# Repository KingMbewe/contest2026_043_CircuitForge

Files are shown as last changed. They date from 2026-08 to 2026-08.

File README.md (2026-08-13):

<b>English</b> | <a href="README_zh.md">中文</a>

# VelaPaw — an on-device AI multi-pet smart feeder

**Team:** CircuitForge (`contest2026_043`) · **Track:** AI Hardware Product Innovation (AI 硬件产品创新)
**Platform:** openVela (NuttX) on a Waveshare **ESP32-S3-Touch-LCD-3.5-C**

---

## Demo Video

<!-- TODO: paste the GitHub-generated CDN URL here after uploading VelaPaw_Demo.mp4 through the GitHub web editor (drag the file into this README's edit box on github.com). GitHub renders it as a native inline player automatically. -->

https://github.com/user-attachments/assets/88f0cb95-1f25-4606-aad2-784a267a6f7b

▶ If the embedded video above doesn't load, [download it directly](VelaPaw_Demo.mp4) (58MB, MP4). We recommend you download the video for better quality.

---

## 1. What it is

**VelaPaw is a smart pet feeder that recognizes *which* pet is at the bowl and dispenses that individual pet's scheduled meal — with every bit of AI running on the device itself. No cloud, no phone, no account.**

In a multi-pet home, a normal timed feeder can't tell the cats apart, so the greedy one eats everyone's food and portion control is impossible. VelaPaw solves this the way a human would: it *looks* at the animal, identifies it, and feeds it only its own ration, at its own mealtimes. Because the camera, the neural networks, the clock, and the dispenser are all self-contained, it keeps working with the internet down and never sends images of your home anywhere.

**Highlights**

- 🐾 **Per-pet identification** — an on-device INT8 neural network recognizes each enrolled pet by face, not by a tag or collar.
- 🍽️ **Recognition-gated feeding** — a pet is fed only when it is *recognized at the bowl* **and** one of *its* meals is due (and not skipped), at most once per meal per day. Each meal slot has its own **skip-meal** toggle.
- 🗣️ **Voice-settable schedules** — meal times can be spoken, not just tapped: a MEAL→HOUR→CONFIRM voice dialog, driven by an on-device keyword-spotting model, sets a pet's feeding schedule hands-free.
- ⚖️ **Portion & daily-limit control** — per-pet gram portions with a hard daily cap.
- 🩺 **Health monitoring** — a second on-device network estimates Body Condition (under / ideal / over), and the feeding-history analytics raise a **sudden-appetite-drop alert**, an early illness sign.
- 🕑 **Real timekeeping** — a hardware RTC keeps schedules accurate across power loss.
- 🌐 **Bilingual UI** — English / 中文, with a live in-app language toggle.
- 💾 **Everything persists** — enrolled pets, schedules, and pet photos survive a power cut.
- 🖥️ **Runs as an appliance** — boots straight into a touchscreen UI; no console needed.

**Why now:** in March 2026, Xiaomi shipped the Mijia Smart Pet Feeder 2 (Visual Edition) — a mass-market feeder (¥449–549, ≈$65–80) that added a camera specifically to bring AI vision into feeding. That's independent, at-scale validation of VelaPaw's founding bet — a camera belongs at the feeder — carried one step further: from watching a bowl to knowing *whose* bowl it is, identified by face and fed entirely on-device with no app, account, or cloud. Full comparison in [§06 Market & Value](VelaPaw_Project_Intro.pdf) of the project intro.

---

## 2. On-device AI (the heart of the project)

Recognition is **open-set metric learning**, not a fixed classifier. The model is a generic pet feature-extractor (MobileNetV3-Small backbone + a spatial-attention *TSFM* module) that turns a camera frame into an L2-normalized 128-D **embedding**. Enrolling a pet stores the averaged embedding of a few photos; recognition is a cosine match against the enrolled pets. This is why **adding a pet needs no retraining** — enrollment is a first-class step, and recognition quality is driven by good enrollment photos rather than a frozen label set.

| | |
|---|---|
| **Identity model** | MobileNetV3-Small + TSFM attention, INT8, 128-D embedding, 128×128 input |
| **Body-condition model** | 3-class (under/ideal/over) INT8 CNN |
| **Runtime** | TensorFlow Lite for Microcontrollers (`apps/mlearning/tflite-micro`) |
| **Acceleration** | ESP-NN SIMD kernels on the Xtensa LX7 → **~1.3 s / inference** (vs ~6.75 s reference) |
| **Where models live** | flash-loaded at runtime (1.4 MB identity @ `0x600000`, 626 KB BCS @ `0x760000`) — too large to memory-map, so read into PSRAM on boot |

Both models were trained off-device with the pipeline in [`host/`](host/) (TensorFlow/Keras → INT8 post-training quantization → `.tflite`).

---

## 3. How it works — from camera to kibble

```
   camera frame ──► embedding (TFLM, INT8) ──► cosine match vs enrolled pets
                                                        │
                                             recognized pet + score
                                                        │
                                        is one of THIS pet's meals due & unfed today?
                                                   │yes            │no
                                              dispense N g      show "next meal 18:00"
                                       (28BYJ-48 stepper, paddle rotor)
                                                   │
                                        log to history · update trends · BCS check
```

The gate in the middle is the whole idea: recognition alone would feed a greedy pet all day; a timer alone would feed whichever animal happened to be standing there. **Both must agree.**

**Software architecture** (clean HAL boundaries, in [`app/velapaw/`](app/velapaw/)):

- `ui/` — LVGL touchscreen UI (Enroll · Recognize · My Pets · Trends)
- `infer/` — inference interface + the TFLite-Micro backend + the trained models
- `identity/` — enrollment store, cosine matcher, per-pet flash persistence, pet photos
- `store/` — feeding history & behavior analytics
- `hal/` — camera (OV5640) and feeder (28BYJ-48 stepper) hardware abstraction

**Board support** ([`board/`](board/)) — a custom board file drives the display, the OV5640 camera via the ESP32-S3 LCD_CAM peripheral, the PCF85063 RTC over I²C, and the feeder's **28BYJ-48 stepper** through a ULN2003 driver on four GPIOs (IN1–IN3/IN4 on GPIO9/10/11/**43**). The display runs over **hardware SPI at 40 MHz with DMA**. The ES8311 audio codec's private I²S bus (GPIO12–16, not routed to any header) drives the onboard mic and speaker for the voice-settable schedules.

---

## 4. Hardware

- **Waveshare ESP32-S3-Touch-LCD-3.5-C** — ESP32-S3, 8 MB PSRAM, 16 MB flash, 320×480 ST7796 touch LCD, OV5640 camera, PCF85063 RTC.

> **Why this board — same SoC, right peripherals.** This board carries the **same ESP32-S3** as the contest-provided ESP32-S3-EYE, so the openVela port, the on-device inference, and every driver are identical work on that chip. What VelaPaw additionally needs is a **capacitive touch display** — enrolling a pet, editing meal schedules and reviewing trends all happen on-screen — and a **real-time clock** so scheduled feeding survives power loss. The ESP32-S3-EYE is a vision/voice development board with a small non-touch screen and no RTC; the Waveshare Touch-LCD-3.5-C integrates the 3.5″ touch LCD, OV5640 camera and PCF85063 RTC the product depends on, in a single board. Same platform, chosen carrier.
- **Feeder** — a **28BYJ-48 stepper**-driven **paddle-rotor** dispenser (via a ULN2003 driver): a vaned rotor meters a fixed pocket of kibble per step, so the portion depends on rotation, not on how full the hopper is. Fully parametric 3D model + printable STLs and BOM in [`hardware/`](hardware/).
- **Camera on a 30 cm FFC** — the OV5640 is unplugged from the board and run out on a 30 cm ribbon + 1:1 coupler to its own **`cam_mast`** yoke in front of the bowl, so the screen faces the owner while the lens watches the pet. (A reversed FFC is fatal on power-on — orientation is meter-verified; see [`hardware/README.md`](hardware/README.md).)

---

## 5. Repository layout

```
app/velapaw/     — the device application (linkfile'd to packages/demos/ by the manifest)
board/           — board files: display/camera/RTC/stepper (esp32s3_st7789.c),
                   auto-start (esp32s3_appinit.c), and the board defconfig
host/            — off-device model training & export (TensorFlow/Keras)
hardware/        — 3D-printable feeder (OpenSCAD source + STLs + BOM)
docs/            — technical notes and benchmark reports
logs/            — AI-Coding session logs (this project was built with AI assistance)
```

---

## 6. Build & run (real hardware)

```bash
# 1. Pull openVela + this team repo
repo init -u https://github.com/open-vela/contest2026_043_CircuitForge \
  -b dev-ai-contest-2026 -m contest2026_043_CircuitForge.xml
repo sync -c -j8

# 2. Place the board files into the ESP32-S3 board tree
BOARD=nuttx/boards/xtensa/esp32s3/esp32s3-devkit
cp contest2026_043_CircuitForge/board/esp32s3_st7789.c   $BOARD/src/
cp contest2026_043_CircuitForge/board/esp32s3_appinit.c  $BOARD/src/
cp contest2026_043_CircuitForge/board/esp32s3_bringup.c  $BOARD/src/
cp contest2026_043_CircuitForge/board/configs/waveshare_lcd/defconfig \
   $BOARD/configs/waveshare_lcd/defconfig

# 3. Build (from the openVela workspace root)
./build.sh esp32s3-devkit:waveshare_lcd -j8

# 4. Flash firmware + the two on-device models
esptool --chip esp32s3 --port <PORT> write-flash \
  0x0        nuttx/nuttx.bin \
  0x600000   contest2026_043_CircuitForge/app/velapaw/infer/model/velapaw.tflite \
  0x760000   contest2026_043_CircuitForge/app/velapaw/infer/model/bcs.tflite
```

On boot the device runs the feeder UI directly. **Enroll a pet** (capture a few tight, well-lit face photos), then the **Recognize** tab identifies it and feeds on schedule.

> **Note on inference speed:** the ~1.3 s figure uses the ESP-NN accelerated kernels. See the [engineering deep-dive](docs/ENGINEERING.md) for the acceleration setup, the hardware-SPI display debug, and reproducibility notes.

---

## 7. AI-assisted development

This project was built end-to-end with AI-assisted (AI Coding) development, and the full session logs are committed under [`logs/`](logs/) as required. AI was used throughout the lifecycle:

- **Requirements & design** — shaping the recognition-gated feeding model, the open-set enrollment approach, and the health-monitoring analytics.
- **Firmware & drivers** — bringing up the display, OV5640 camera (LCD_CAM), RTC, and the 28BYJ-48 stepper feeder on the ESP32-S3; wiring TensorFlow Lite Micro + ESP-NN onto the Xtensa LX7.
- **Hard debugging** — the standout example: a hardware-SPI display bug that survived ~60 blind build cycles was cracked with a **logic analyzer**, root-caused to the CS-tied-low panel losing bit-sync at the pad handover, and turned into a **display speedup** (bit-bang → hardware SPI + DMA).
- **Product iteration** — the full pet lifecycle (enroll, recognize, feed, edit, delete, photos), all tested on real hardware.

---

## 8. Status

**Working on hardware today:** on-device recognition, body-condition scoring, recognition-gated 3-meals/day scheduling with a per-slot skip-meal toggle, portion & daily-limit control, feeding history & trends with appetite-drop alerts, hardware RTC, full pet lifecycle with persistent photos, auto-start, a hardware-SPI + DMA display, a bilingual EN/中文 UI with a live toggle, a spoken MEAL→HOUR→CONFIRM meal-scheduling dialog (hardware-proven end to end), the **28BYJ-48 stepper feeder** (turning on GPIO9/10/11/43), the **OV5640 relocated onto a 30 cm FFC** and confirmed working through the coupler + `cam_mast` mount, and the **3D-printed enclosure fully assembled** — stepper dispenser and relocated camera mounted into the printed structure.

---
## 9. Datasets
Datasets used in this project are found at: https://drive.google.com/drive/folders/1-HnbS-VStbKuXCXWK-O1Nh2lNLdqMpbI?usp=sharing. 

*Built by team CircuitForge for the 2026 openVela AI Hardware Developer Contest.*

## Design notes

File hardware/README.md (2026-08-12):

# VelaPaw — feeder hardware

Gravity hopper → **paddle rotor** → chute → bowl, driven by a **28BYJ-48 stepper** (via a ULN2003 board), with **IN4 on GPIO43**.

## Why a rotor and not a flap

A flap's dose depends on how long it stays open **and** how full the hopper is — the same 800 ms drops noticeably more food when the hopper is heavy. A rotor pocket holds a fixed volume, so the dose depends only on how many pockets you index. Since the product claim is *per-pet portion control*, a mechanism that drifts as the hopper empties would quietly undermine it.

The rotor is driven by a **28BYJ-48 stepper** (via a ULN2003 board), which rotates **continuously in one direction** — so pockets ratchet inlet→outlet and per-pocket dosing is exact:

```
grams = pockets × GRAMS_PER_POCKET
```

> **Why a stepper, not a servo.** An MG90S servo can only *oscillate*, and with the inlet and outlet 180° apart a zero-net-rotation wobble can never carry a pocket across — it dispenses the initial charge then dead-heads. The stepper's continuous spin is what makes the rotary valve actually work, and it makes the portion-control claim literally true. (The geared 28BYJ-48 also has strong low-speed torque, which resists kibble jams.)

## Bill of materials

| Item | Notes |
|---|---|
| **28BYJ-48 stepper + ULN2003 driver** (5 V bundle) | The **5 V** version — runs off the same 5 V supply below. Get the motor+driver bundle. |
| **5 V supply, ≥2 A** | Powers the ULN2003/motor. Common **ground** with the ESP32; never tie the 5 V rails together. |
| Female–female jumpers | 4 signal lines (IN1–IN4) + 5 V + GND to the ULN2003. |
| PLA / PETG (or JLC nylon) | PLA is fine for dry kibble; PETG/nylon if you want to wash the parts. |

The **ULN2003 board is the driver** — no separate PWM chip; the ESP32-S3 just toggles 4 GPIOs through the half-step sequence. (No servo → the 470 µF servo-inrush cap is no longer needed.)

## Wiring

```
  ESP32-S3 (3.3 V logic)            ULN2003 driver board          28BYJ-48
    GPIO9  ─────────────────────────> IN1
    GPIO10 ─────────────────────────> IN2                         (5-pin
    GPIO11 ─────────────────────────> IN3            motor  ────►  connector)
    GPIO43 ─────────────────────────> IN4
                                      +   ◄── 5 V PSU +
                                      −   ◄──┬─ 5 V PSU −
  board GND ───────────────────────────────┘   ← COMMON GROUND, mandatory
```

- **IN1–IN3 = GPIO9/10/11** (header J8 pins 14/12/10), shared with the unused microSD slot (its CS is on expander EXIO3 and stays deasserted, so it's safe to drive). **Never put these on GPIO12/13/14/15/16** — those are the ES8311 audio codec's private I²S bus, not routed to any header at all, and VelaPaw now uses them for voice-settable meal schedules (onboard mic + speaker). Putting the stepper there would silently short-circuit the coil drive against the audio path — this used to be write-up guidance from before audio bring-up and is now out of date.
- **IN4 = GPIO43** (U0TXD). This works because the console runs on the **USB-Serial/JTAG** port, not UART0, so U0TXD is free to drive. **Use GPIO43, not GPIO44** — GPIO44 (U0RXD) is clamped and the coil won't drive cleanly (this was the cause of the early "stepper buzzes but won't turn" during bring-up; it was the pin, not the coil order).
- Change any of these in the board file (`STEP_IN1..4`) if you ever need UART0.
- **Power the ULN2003 from the separate 5 V supply, not the board**, and share **ground only**. The 28BYJ-48 draws ~240 mA/phase — fine for a 2 A supply.
- The ULN2003's on-board LEDs show the coil sequence — handy for confirming it's stepping.

## Printing

All parts print without supports. PLA/PETG, 0.2 mm layers, 3 perimeters.

```bash
openscad -D 'part="rotor"'         -o rotor.stl         velapaw_feeder.scad
openscad -D 'part="housing"'       -o housing.stl       velapaw_feeder.scad
openscad -D 'part="plate_stepper"' -o plate_stepper.stl velapaw_feeder.scad   # drive end (28BYJ-48)
openscad -D 'part="plate_idle"'    -o plate_idle.stl    velapaw_feeder.scad
openscad -D 'part="hopper"'        -o hopper.stl        velapaw_feeder.scad
openscad -D 'part="cam_pod"'       -o cam_pod.stl       velapaw_feeder.scad   # relocated OV5640 enclosure
openscad -D 'part="cam_mast"'      -o cam_mast.stl      velapaw_feeder.scad   # drum-front camera yoke
```

`plate_servo` still exists as legacy reference but is **not** printed — the drive
end is the stepper (`plate_stepper`). The pre-batched print/order set for the
structural parts (base, pedestal, chute, cradle, cam pod + mast) lives in
[`stl_jlcpcb/`](stl_jlcpcb/) with an [`ORDER.md`](stl_jlcpcb/ORDER.md).

Open the file with no `-D` (`part="product"`) to preview the whole assembly.

## Board cradle (mounting the ESP32-S3-Touch-LCD-3.5-C)

`board_cradle` holds the Waveshare board so the **screen faces the owner** (the
board is now un-rotated — the front-eye layout). The board drops into the tray and
is fixed with four **M2.00** self-tapping screws through its corner mounting holes,
cutting into the posts' printed pilot holes; the bottom GPIO header (and the
stepper **IN4 wire on GPIO43**) exits through the header slot.

The OV5640 **no longer looks down through a window in the cradle** — it has been
**decoupled from the board and relocated** (see *Camera relocation* below), so the
screen can face the owner while the camera watches the bowl from its own mount.

Dimensions are taken from the Waveshare -C outline drawing (95.11 × 63.67 × 14.1 mm,
corner R7.3, mounting holes 72.00 × 48.50 mm apart, camera centred). `BM_SCREW_D`
(a 1.7 mm self-tap pilot bore for **M2.00** screws — the bare-board drawing labels
the mounting holes M2.00, not M2.5 as earlier assumed) is confirmed from the
drawing. **One value is still not on the drawing and remains assumed — verify on
the real board before printing:** `BM_CAM_WIN` (camera lens-barrel diameter,
assumed Ø14). Both constants are near the bottom of the `.scad`.

> ### Stepper mechanical parts — done (verify two dimensions)
> The drive end is now built for the **28BYJ-48**: print **`plate_stepper`** (its
> Ø28 body clears the central bore; it bolts on through the two 35 mm flange
> holes) — *not* `plate_servo`, which is kept only as legacy reference. The
> **rotor** now has a **5 mm double-D socket** in its driven face that presses
> straight onto the stepper shaft (no horn/spline). Body Ø is confirmed 28 mm;
> two values are nominal — **caliper before printing** and adjust at the top of
> the `.scad`: `STEP_SHAFT_FLAT` (shaft width across the flats) and
> `STEP_SHAFT_LEN` (shaft length). `housing`, `plate_idle`, `hopper` and
> `board_cradle` are unchanged.

## Camera relocation (OV5640 on a 30 cm FFC)

The OV5640 plugs into the board's 24-pin 0.5 mm DVP connector (schematic **J2**,
"0.5-24pin-cam"). Unplugging it and running a **30 cm FFC + a 1:1 coupler** lets
the camera live on its own mount instead of riding the board, so the screen can
face the owner while the lens watches the bowl. The camera sits in **`cam_pod`**
(open-back OV5640 enclosure) carried by **`cam_mast`** — a two-leg yoke that
straddles the chute and holds the pod just in front of the drum, aimed steeply
down-and-forward at the pet (the sightline passes *under* the owner-facing
screen's bottom edge). `cam_mast` bolts to `base_front` with 2× M3.

> **⚠️ A reversed FFC is FATAL on first power-on** — board pin *N* would meet
> camera pin *25−N*, dead-shorting a power rail into a data/ground pin. **Verify
> orientation with a meter before powering.** Verified-good chain (2026-07-30):
>
> ```
> camera pin 1 → pigtail "1" → coupler P1.1 (left) → P2.1 (left)
>              → 30 cm cable pin-1 (dotted edge) → J2 pin 1 (BOTTOM end of J2)
> ```
>
> Key facts for this module: the **coupler is a straight 1:1 extender** (silk
> `1`-left / `24`-right on both ports), **J2 pin 1 = the bottom end** (board silk
> prints `24` at the top), and the camera's **grounds are not bonded internally**
> — so you can't confirm orientation by probing *through* the camera; trust the
> silkscreen `1`/`24` marks and bare-copper (`000.x`) continuity only. Keep the
> ~30 cm run in a small **service loop** at the yoke foot for strain relief, and
> route it away from the stepper leads to keep noise off the DVP clock/data lines.

## Assembly

1. Mount the **28BYJ-48** to `plate_stepper` (flange screws).
2. Press the rotor's **D-socket** onto the stepper shaft.
3. Drop the rotor into the `housing` bore.
4. Fit `plate_idle` on the far end — its boss is the rotor's stub axle.
5. Bolt both plates to the housing (4 × M3).
6. Plug the `hopper` spigot into the inlet; put a bowl under the outlet.

## Calibration — do this once

1. Fill the hopper.
2. Dispense a single pocket.
3. Weigh what lands in the bowl.
4. Put that number in `GRAMS_PER_POCKET` in `board/esp32s3_st7789.c` and rebuild.

Portions are then correct at any hopper level, for the life of the machine. If you want a different dose granularity, change `WIDTH` in the `.scad` (pocket volume scales linearly with it) and re-calibrate.

`POCKETS` in the `.scad` must always equal `ROTOR_POCKETS` in the board file.

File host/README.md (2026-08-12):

# VelaPaw host pipeline — train & export the on-device embedding model

Off-device Python (TensorFlow) that produces the INT8 `.tflite` embedding model
the device app runs via `infer/backend_tflm.cc`. Run on a GPU machine, **not**
in the openVela build.

## Approach (IMPLEMENTATION_PLAN.md §4)

Open-set identity by **embeddings**, not N-way softmax: a backbone produces a
fixed-length L2-normalized embedding; identity = cosine similarity vs. enrolled
pets. Training uses a margin head (ArcFace) over known classes; **only the
backbone→embedding sub-model is exported** (the head is training-only). This lets
new pets be enrolled on-device without retraining.

Two interchangeable models for the benchmark panel:
- **fast** — MobileNetV3-Small backbone + embedding head.
- **accurate** — same + an attention module (the operator's TSFM thesis block;
  a placeholder insertion point is provided — replace it).

## Pipeline

```bash
pip install -r requirements.txt

# 1. Train (fp32 checkpoint). See data/README.md for dataset layout.
python train_embedding.py --variant fast     --data data/train --epochs 30
python train_embedding.py --variant accurate --data data/train --epochs 30

# 2. INT8 quantize + export -> .tflite + C array + meta.json
python quantize_export.py --variant fast     --repr data/repr
python quantize_export.py --variant accurate --repr data/repr

# 3. Check the embedding separates identities (and pick THRESHOLD)
python eval_separability.py --variant accurate --data data/val
```

Outputs land in `export/<variant>/`:
`<variant>.tflite`, `<variant>_model_data.{cc,h}` (C array), `meta.json`
(input shape, normalization, embed dim, suggested threshold).

## Wiring the model into the device

`backend_tflm.cc` currently embeds `person_detect` (placeholder). To use a real
model: point the model-gen at `export/<variant>/<variant>.tflite`, set
`VELAPAW_EMBED_DIM` to `meta.json:embed_dim`, match the device preprocessing to
`meta.json` (input size / channels / normalization), and extend the TFLM
`MicroMutableOpResolver` in `backend_tflm.cc` to cover the model's ops.

> **TFLM op-support caveat (plan risk #2):** MobileNetV3 uses hard-swish and
> squeeze-excite (→ HARD_SWISH, MUL, ADD, LOGISTIC, MEAN ops). Verify every op
> is in TFLite-Micro before committing the accurate model; `quantize_export.py`
> prints the op list. If unsupported, use `--no-hardswish --no-se` (relu, no SE)
> for a TFLM-safe variant.

> **Latency caveat:** absolute inference time must be measured on the ESP32-S3
> (LX7), not the emulator. See docs/TFLM_SPIKE_REPORT.md.

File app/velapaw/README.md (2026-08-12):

# VelaPaw — multi-pet recognition smart feeder (contest2026_043)

On-device app: a camera recognizes *which individual pet* is at the bowl and
dispenses that pet's portion, with per-pet cooldown and feeding history.
Everything runs on-device (no cloud).

This directory is the **device application**. It is exposed into the openVela
build tree via a manifest `<linkfile>`:

```
app/velapaw  ->  packages/demos/contest2026_043_velapaw
```

## Status: running on real hardware

This app now runs on the real **Waveshare ESP32-S3-Touch-LCD-3.5-C** with all the
platform pieces backed by real drivers. The same clean HAL boundaries still keep
an **emulator build** working (mocks/stubs), so it can compile and run under QEMU
without a board — each HAL just selects its backend at build time:

| Module | Emulator backend | Hardware backend (shipping) |
|---|---|---|
| `hal/camera.*` | `camera_mock.c` (synthetic scenes) | **OV5640** via the board's LCD_CAM driver (on a 30 cm FFC to the `cam_mast` mount) |
| `infer/infer.*`  | `infer_stub.c` **or** `backend_tflm.cc` (TFLM INT8, `CONFIG_VELAPAW_INFER_TFLM`) | **`backend_tflm.cc`** — host-trained INT8 embedding model, ESP-NN accelerated (~1.3 s) |
| `identity/` | real cosine match + in-memory enroll | same, **persisted to flash** (`0x800000`) |
| `store/` | `store_stub.c` (in-memory) | feeding history + analytics persisted to flash |
| `hal/feeder.*` | `feeder_mock.c` (logs dispense) | **28BYJ-48 stepper** via ULN2003 (GPIO9/10/11/**43**) |

The real-hardware build (board files, flashing firmware + the two models) is in
the [root README](../../README.md); the emulator flow is below.

## Build

```bash
source /d/openVela/vela-env.sh
cd /d/openVela/nuttx
kconfig-tweak --file build/.config -e LVX_USE_DEMO_CONTEST2026_043_VELAPAW
# optional: real TFLite-Micro inference path (needs CONFIG_TFLITEMICRO):
kconfig-tweak --file build/.config -e VELAPAW_INFER_TFLM
vela_olddefconfig
cmake -B build -DBOARD_CONFIG="$VELA_BOARD_CONFIG" -GNinja
cmake --build build -j8
```

Run the emulator and at the `nsh>` prompt: `velapaw`. With the TFLM backend it
prints real per-inference latency + tensor-arena (measured ~82 KB arena,
~0.3 s/inference on the emulated cortex-a15 — not an ESP32-S3 figure).

## Pipeline (velapaw_main.c)

`init -> enroll demo pets -> loop: capture -> presence gate -> embed -> match ->
(cooldown ok?) dispense + log`.

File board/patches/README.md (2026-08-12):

# Audio patches (nuttx / apps)

These patch **upstream files outside this repo**, so a `repo sync` silently
reverts them and the audio path stops working with no error. They are kept here
because this repo is the only thing that survives a re-sync.

Captured 2026-08-03 from the working tree, against a verified-good capture run.

| File | Target checkout | Files touched |
|---|---|---|
| `velapaw-audio-nuttx.patch` | `nuttx/` | `arch/xtensa/src/esp32s3/esp32s3_i2s.c`, `drivers/audio/es8311.c` |
| `velapaw-audio-apps.patch` | `apps/` | `system/nxlooper/nxlooper.c` |

## Apply

```bash
cd ~/openvela/nuttx && git apply --check ../contest2026_043_CircuitForge/board/patches/velapaw-audio-nuttx.patch \
  && git apply ../contest2026_043_CircuitForge/board/patches/velapaw-audio-nuttx.patch
cd ~/openvela/apps  && git apply --check ../contest2026_043_CircuitForge/board/patches/velapaw-audio-apps.patch \
  && git apply ../contest2026_043_CircuitForge/board/patches/velapaw-audio-apps.patch
```

`--check` first — a partial apply is worse than no apply.

Note these do **not** cover the esp-hal `LOCK_INITIALIZER_UNLOCKED` → `SP_UNLOCKED`
fix, which lives in a tree that is re-cloned *during* the build. That one still
needs `~/fix_vm_patches.sh`, and the ordering is **build → fix → build**, never
fix → build.

## What's load-bearing

- **RX TDM slot map** (`i2s_configure`) — `i2s_rxchannels()` is a pure no-op
  upstream, so RX sat at `TOT_CHAN_NUM=0` (one slot per frame) while `RX_CONF1`
  described a two-slot frame. The receiver completed frames and discarded every
  slot: `nbytes=0` forever. This is the single fix that made capture work.
- **`I2S_RX_MONO`** (`I2S_RX_CONF_REG` bit 5) — `es8311_start` sets
  `GPIO_REG44=0x50`, putting the mic on the left slot and *the DAC's own output*
  on the right. With both RX slots enabled, playback fed straight back into the
  record stream — a digital feedback loop independent of acoustics.
- **`nbytes &= ~3`** in `i2s_receive` — re-aligns after the `DMA_BUFLEN_MAX`
  clamp, which can leave a non-multiple of the sample width.
- **`priv->streaming = true`** in `i2s_receive`.
- **Gain chain** in `es8311.c`: `SYSTEM_REG14=0x18` (24 dB analog PGA, was
  `0x1a` = 30 dB max) and `ADC_REG16=0x20` (0 dB digital, was `0x24` = 24 dB).
  Stock total was 54 dB, which railed the ADC on every buffer — the clipping
  *was* the "noise". Do not raise these.
- **`es8311_configure` returning `-ERANGE` on success** — upstream bug; `ret` is
  pre-loaded `-ERANGE` and the clearing expression never fires.
- **`#include <nuttx/mutex.h>`** in both files — missing upstream; without it
  `nxmutex_lock`/`unlock` become extern calls that can never link, because
  `CONFIG_LIBC_SEM_MUTEX_NOINLINE` is off and they are `static inline`.

## ⚠️ Strip before shipping

The nuttx patch also carries **diagnostics only**, which must come out of the
release build:

- `VP: mic` — the per-buffer meter in the RX worker (`peak`/`mean`/`dc`/`rail`).
- `VP: RXDUMP` — the one-shot register dump in `i2s_tx_worker`.

Both are `syslog(LOG_ERR, ...)` on every capture buffer and are noisy enough to
affect timing. They are thread context, so `syslog` is safe there — do **not**
move either into ISR context, which faults on this board (`EXCCAUSE=0x14`).

Matching cleanup in the defconfig: `CONFIG_DEBUG_AUDIO`, `_ERROR`, `_WARN`,
`CONFIG_DEBUG_FEATURES`, `CONFIG_SYSLOG_CONSOLE`.

## The `nxlooper` changes

`velapaw-audio-apps.patch` is almost entirely `VP: L*`/`VP: M*` instrumentation
plus the silence-priming of TX before the record loop starts. It is a **bring-up
harness, not product code** — VelaPaw never runs `loopback`. Nothing here needs
to survive into the release build; keep it only for reproducing the audio tests.

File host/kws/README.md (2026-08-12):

# VelaPaw KWS — training the scheduling vocabulary

Trains the keyword-spotting model that lets an owner set a feeding time by
voice. Replaces the upstream Colab notebook with a staged, resumable script.

```
host/.venv/Scripts/python.exe host/kws/train_kws.py all
```

---

## Why there is no recording session

`docs/AUDIO_PLAN.md` Phase 2 originally specified recording ~10–15 words
yourself, through this mic, in the printed enclosure, with the stepper running —
and rated the result *"roughly a coin flip"* against the schedule. That risk was
priced against building a dataset from scratch.

It turns out not to be necessary. **Google Speech Commands v0.02** (Pete Warden,
2018 — 105,829 one-second 16 kHz clips, 2,618 speakers, 35 words, CC BY 4.0)
already contains every word the scheduling dialog needs:

| dialog step | words | in dataset? |
|---|---|---|
| hour | `zero`–`nine` | ✅ |
| confirm | `yes`, `no` | ✅ (already shipping) |
| meal slot | `one`, `two`, `three` | ✅ (reuses the digits) |
| **pet** | — | **not spoken — the camera identifies the pet** |

The words the dataset *lacks* — "schedule", "breakfast", a wake word — are
exactly the ones a button and three numbered meal slots replace at no cost.

This is also not a new dependency: the model already on the board
(`micro_speech`, yes/no at 0.98 live) was trained on this same dataset. The
domain gap between crowdsourced laptop-mic audio and an ES8311 in a printed
enclosure is therefore **measured, not hypothetical** — and survivable.

## Vocabulary and label order — load-bearing

```python
WORDS = ["yes", "no", "zero", "one", ..., "nine"]
```

`input_data.prepare_words_list()` returns `[_silence_, _unknown_] + wanted_words`,
so the label map is:

```
 0 _silence_    1 _unknown_    2 yes     3 no
 4 zero   5 one   6 two   7 three   8 four
 9 five  10 six  11 seven 12 eight  13 nine
```

Keeping `yes,no` first means the device enum in `app/velapaw/voice/kws.h` is
**extended, not renumbered** — `VELAPAW_KWS_YES = 2` and `NO = 3` stay valid, so
build 54's code keeps working. Reordering `WORDS` without editing `kws.h` would
make the board confidently report the wrong word, with nothing in the logs to
suggest why.

The ~23 dataset words we don't ask for are folded into `_unknown_`
automatically, which is free negative training data.

## Feature geometry must match the board

`PREPROCESS='micro'` selects TF's `audio_microfrontend` op — the same algorithm
the on-device `audio_preprocessor_int8` model implements. Verified equal:

| | training | device (`kws.h`) |
|---|---|---|
| frames | 49 | `VELAPAW_KWS_FEATURE_COUNT` 49 |
| mel bins | 40 | `VELAPAW_KWS_FEATURE_SIZE` 40 |
| fingerprint | 1960 | 49 × 40 |
| sample rate | 16000 | `VELAPAW_KWS_SAMPLE_RATE` |
| window / stride | 30 / 20 ms | `DURATION_MS` / `STRIDE_MS` |

Changing any of these here without changing `kws.h` (and regenerating the
preprocessor model) silently desynchronises training from inference.

## Environment

`host/.venv` — Python 3.11.9, TensorFlow 2.15.1, numpy 1.26.4. The same env that
trained the vision models; nothing new to install.

**Training is CPU-only.** TensorFlow dropped native Windows GPU support after
2.10, and this venv holds the `tensorflow-intel` wheel — `is_built_with_cuda()`
is `False`, so the RTX 4060 is invisible to it. `tiny_conv` is one conv plus one
FC, and the real bottleneck is per-batch MFCC of the WAVs (CPU-bound even on a
GPU run), so 18,000 steps is an overnight job, not an intractable one.

If you want the GPU involved: **WSL2** (TF 2.15 GPU works there) or **Google
Colab** (free T4; the upstream notebook this derives from was built for it, but
you re-download 2.4 GB per session and long runs hit the idle timeout).

### The `models` shadowing trap

`host/models/` is where the vision pipeline writes its exports. It is a bare
directory, which Python 3 treats as a namespace package — so a plain
`import models` from `host/` resolves to *that* instead of
`speech_commands/models.py` and dies with a bewildering
`module 'models' has no attribute 'prepare_model_settings'`.
`_import_speech_commands()` inserts the vendored dir first **and asserts the
resolved path**, so a subtler version of this can't cost an overnight run.

## Stages

| stage | what it does | cost |
|---|---|---|
| `prep` | download + verify dataset against published clip counts | ~2.4 GB, once |
| `train` | 15,000 + 3,000 steps, checkpoint every 1,000 | **overnight** |
| `freeze` | checkpoint → SavedModel | seconds |
| `convert` | SavedModel → float + int8 `.tflite` | ~1 min |
| `evaluate` | accuracy of both on the held-out test split | ~2 min |

### `prep` checks counts, not existence — and this is not paranoia

A missing word is the easy case: `input_data` would quietly fold it into
`_unknown_` and train a model that can *never* emit it. The case that actually
bit us is worse. A killed download left `four/` holding **269 of its 3,728
clips** — the folder existed, was non-empty, and passed every "is it there"
check. Training would have run overnight on 7 % of a class and the symptom
would have surfaced on the board.

So `prep` asserts each word against its published count (95 % floor) plus the
105,829 total, and prints what it saw either way.

**A short extraction cannot be repaired by re-running `prep`.**
`input_data.py:219-240` nests the `extractall()` *inside* `if not
gfile.Exists(tarball)`, so once the 2.4 GB `.tar.gz` is on disk the extract is
skipped forever and a half-unpacked tree looks cached. Repair by hand — and
note the archive members are `./`-prefixed, so a bare name silently matches
nothing:

```bash
cd host/kws/dataset
tar -xzf speech_commands_v0.02.tar.gz ./four ./stop ./up      # NOT `four stop up`
```

Re-running `train` restarts from zero. To resume a partial run, pass
`--start_checkpoint` to `speech_commands/train.py` by hand.

## The go/no-go gate

`evaluate` prints overall and per-label accuracy for the int8 model — the one
that actually runs on the board.

| result | action |
|---|---|
| **≥ 90 %** | proceed to embedding |
| 85–90 % | usable; expect more "say again" in the dialog |
| **< 85 %** | stop — don't spend device time on it |

Expect the digits to score below yes/no. `three`/`free` and `nine`/`five` are
genuinely close, far closer than `yes`/`no`. The dialog's confirm step exists to
absorb exactly this, and the AM/PM confirm rides along on it for free.

Treat 90 % as a target, not a prediction: the ~91 % figure quoted upstream for
`tiny_conv` is at **4** labels. This architecture is essentially one 4000×N
fully-connected head, and ten confusable digits is a much harder problem than
yes/no/silence/unknown.

### Result, 2026-08-05 — and why 80.85 % is a PASS

18,000 steps, 84.2 % final validation. On the held-out test split (n=5623):
**float 80.90 %, int8 80.85 %** — quantisation cost 0.05 points. Model 59,024 B.

That is under the 85 % line above, and the line is measuring the wrong thing.
Almost the whole deficit is one class the product never has to name:

```
_silence_ 95.4    _unknown_ 34.1    yes 91.6   no 82.5
zero 90.4  one 80.2  two 72.6  three 84.2  four 72.8
five 82.2  six 91.1  seven 87.9  eight 81.1  nine 80.6
```

**VelaPaw never makes a 14-way decision.** Every capture happens inside a dialog
step that already knows its legal answers, so the honest measure is argmax over
that subset:

| step | words | int8 |
|---|---|---:|
| MEAL | one / two / three | **95.68 %** |
| HOUR | zero … nine | **84.95 %** |
| CONFIRM | yes / no | **97.45 %** |

The confusions inside HOUR are the predicted ones: `four`→`two` ×33,
`five`→`nine` ×38, `nine`→`one` ×23.

### Threshold on the RAW probability, not the renormalised one

A constrained argmax always emits *something*, so the accept test carries as
much weight as the model. The obvious choice — renormalise over the legal
subset, `p_best / Σp_legal` — is a good separator between legal words and a
**terrible** rejector of everything else, because renormalising discards the
probability mass sitting on `_unknown_`, which is exactly the mass that means
"that wasn't one of my words." Measured against silence + out-of-vocabulary
clips it lets **86 % of junk through at CONFIRM**.

Thresholding the raw softmax probability of the best legal word keeps that mass
in the denominator. Lowest raw threshold holding junk false-accept ≤ 5 %:

| step | raw p ≥ | accept rate | of accepted, correct | junk through |
|---|---:|---:|---:|---:|
| MEAL | 0.45 | 74.8 % | **99.24 %** | 4.8 % |
| HOUR | 0.73 | 64.6 % | **96.87 %** | 4.9 % |
| CONFIRM | 0.59 | 80.7 % | **99.55 %** | 4.9 % |

Rolled up over one dialog with up to three tries per step: MEAL lands right
97.7 %, HOUR 92.6 %, a wrong time reaches the confirm screen 3.7 % of the time —
where the owner reads it and says "no" — so a **wrong feeding time is actually
saved in 0.017 % of dialogs**. The residual cost is 6.0 % of dialogs abandoned
after three tries somewhere, which is a "say again" problem, not a correctness
one. HOUR's threshold is the dial: dropping it to 0.60 buys 11 points of accept
rate for 3 points of junk.

**Verdict: proceed to embedding.** `conv` would cost a PSRAM arena bring-up and
a widened resolver to attack per-word digit confusability that the confirm step
already absorbs.

Two things these numbers do *not* cover: the clips are crowdsourced laptop-mic
audio, so on-board figures through the ES8311 in a printed enclosure will be
lower — measure per-digit confidence on hardware and re-tune the three
thresholds there — and Speech Commands skews US English.

### If it misses — the fallback ladder, measured at 14 labels

| architecture | params | ~int8 | first-conv activation | new ops |
|---|---:|---:|---:|---|
| `tiny_embedding_conv` | 7,134 | 7 KB | small | none |
| **`tiny_conv`** (current) | **56,662** | **55 KB** | 25×20×8 = **4 KB** | — |
| `conv` | 622,222 | 608 KB | 49×40×64 ≈ **125 KB** | `MAX_POOL_2D` |
| `low_latency_conv` | 877,208 | 857 KB | large | none |

**Flash is not the constraint.** The firmware region runs 0x0 → 0x600000 before
the vision model and the binary ends around 0xF8B88, so even `conv` fits. **The
arena is.** `tiny_conv` fits an 8 KB arena because its activations are 4 KB;
`conv` would force a PSRAM arena *and* a widened resolver. That is a bring-up,
not a swap.

So in the 85–90 % band the cheap moves are per-word thresholds and leaning on the
confirm step — not a bigger model. Reach for `conv` only below ~80 %, where the
dialog genuinely would not work.

If the digits are weak **on-device** despite good test accuracy, the cause is
likely accent — Speech Commands skews US English. The fix is fine-tuning on a
few hundred of your own utterances on top of this model, which is hours of work,
not a restart.

## What happens after a good model

```bash
python3 host/gen_model_data.py \
    --input  host/kws/models/kws_int8.tflite \
    --symbol g_micro_speech_quantized_model_data \
    --outdir app/velapaw/voice/gen
```

Then on the device side:

1. `voice/kws.h` — `VELAPAW_KWS_CATEGORIES` 4 → 14, append the digit labels
2. `voice/kws.cc` — extend the label-name table
3. 🔴 **Register `AddConv2D()`, not `AddDepthwiseConv2D()`.** The shipped
   micro_speech model used a depthwise conv; `tiny_conv` emits a plain
   `CONV_2D`. The resolver stays `<4>` — same slot count, different op — and
   getting it wrong is not a link error, it's `AllocateTensors` failing at boot
   with "Didn't find op for builtin opcode".
4. `KWS_CLASSIFIER_ARENA` 8 KB → **16 KB**. The conv activation is 25×20×8 =
   4000 B and the flattened 4000 B feeding `final_fc` is live alongside the
   1960 B input, so the peak is ~10 KB against 6916 B before. The board prints
   `arena used N/16384` at init — shrink to the measured number, don't guess.
5. **Leave `CONFIG_VELAPAW_KWS_SELFTEST` on for the first boot.** An earlier
   note here said to turn it off because its vectors assert 4-label indices.
   That was wrong: the two bit-exactness vectors test the *frontend* graph,
   which did not change, and the end-to-end clips assert
   `VELAPAW_KWS_YES`/`NO`/`SILENCE` = 2/3/0, which the label order deliberately
   preserved. It is the cheapest end-to-end check of the new classifier on
   known audio. Turn it off afterwards for the ~98 KB of canned clips.

Model size grows from 18,800 B to **59,024 B**. The `final_fc` head is
4000 × n_labels and dominates.

## Provenance

`speech_commands/` is vendored from
`tensorflow/tensorflow` at tag **`v2.15.0`** — matching the installed TF 2.15.1,
so there is no version drift:

```
train.py  models.py  input_data.py  freeze.py
```

Vendored rather than cloned so the pipeline is reproducible and reviewable
in-repo, and doesn't depend on the state of TensorFlow master.

Dataset: <https://storage.googleapis.com/download.tensorflow.org/data/speech_commands_v0.02.tar.gz>
(CC BY 4.0 — attribution belongs in the project's licence notes).

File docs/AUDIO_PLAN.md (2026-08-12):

# VelaPaw — Voice Control Plan (ES8311 onboard mic)

Status: **largely working on hardware.** Written 2026-08-02, after the schematic
netlist review that proved the onboard mic is reachable without touching the
stepper — the plan below (phases 0–3) is now history, not a roadmap. The MEAL→HOUR→
CONFIRM voice-scheduling dialog has been proven end to end on hardware (builds
68/69/81, 2026-08-06/07); the console-blocking bug that required a PC on COM4 was
solved in build 83 (2026-08-07). One issue remains open — an intermittent I²S
capture stall (`-110`) that a RESET tap reproduces but a cold boot doesn't reliably
clear — and the build currently flashed on the board (`skipmeal`, built on `b82r`)
predates the b83 fix, so its mic fails every capture. See `docs/SESSION_STATE.md`
("Voice & audio — current status") for the up-to-date picture and build lineage;
treat everything below this point as the historical bring-up log that got it there.

## Why this is possible at all

The ES8311 codec's I²S bus is **GPIO 12/13/14/15/16**, and those nets are private —
each has exactly two nodes, the ESP32 and the codec. They are not on header J8, so
nothing external can reach them *or* conflict with them. The stepper lives on
9/10/11/43 (header pins 14/12/10/27). Audio and the feeder cannot collide
electrically. See `SESSION_STATE.md` for the full J8 map.

The mic is analog-differential into `MIC1P`/`MIC1N`; the bundled 6 Ω 1 W speaker runs
through an NS4150B amp whose enable is `PA_CTRL` = expander **EXIO7**. Codec control
shares the existing IO7/IO8 I²C bus. **No new parts, no new wiring.**

---

## PHASE 0 — Rollback net ✅ DONE (2026-08-02)

No git. Deliberate call: the repo has one scaffold commit and all real work untracked,
and rather than sweep months of work into a single opaque commit right before a risky
change, the rollback net is **plain file copies** — a golden binary in the VM plus a
source snapshot on Windows.

### Leg 1 — Golden binary ✅ (the one that actually saves you)

The firmware currently on the board, copied out of the VM to a path nothing touches,
md5summed and `chmod a-w`:

```
~/velapaw-golden/pre-audio/
  nuttx.bin            816,308 B   built 2026-07-24 10:51:26
  defconfig.golden      79,066 B   the VM's full nuttx/.config
  defconfig.board        2,894 B   board/configs/waveshare_lcd/defconfig
  esp32s3_st7789.c      42,037 B   ← AUTHORITATIVE stepper source
  esp32s3_appinit.c
  MANIFEST.md5
```

Verified as the exact image running on the board: the build is sequential and
self-consistent (`.o` 10:51:19 → `.built` 10:51:23 → `nuttx` ELF 10:51:25.722 →
`nuttx.bin` 10:51:26.022) and no app source is newer than it.

Rollback, ~60 seconds, no rebuild:

```bash
esptool --chip esp32s3 --port <PORT> write-flash \
  0x0      ~/velapaw-golden/pre-audio/nuttx.bin \
  0x600000 <repo>/app/velapaw/infer/model/velapaw.tflite \
  0x760000 <repo>/app/velapaw/infer/model/bcs.tflite
```

⚠️ **Remaining gap:** the two `.tflite` models are *not* in the golden directory — the
`cp` silently failed because the contest repo isn't checked out at that path in the VM.
They are safe on Windows and are in the snapshot, but the golden set is not yet
self-contained. To close it:

```bash
chmod u+w ~/velapaw-golden/pre-audio
cp <repo>/app/velapaw/infer/model/{velapaw,bcs}.tflite ~/velapaw-golden/pre-audio/
cd ~/velapaw-golden/pre-audio && md5sum * > MANIFEST.md5 && chmod -R a-w .
```

### Leg 2 — Source snapshot ✅ (Windows)

`D:\openVela\velapaw-snapshots\2026-08-02-pre-audio\` — 215 files, 20.9 MB, the repo
minus `.git/`, `host/.venv/`, `host/data/`, `host/export*/`, `logs/`, and build
artifacts. See its `RESTORE.md`. Restore = copy directories back over the working tree.

### Leg 3 — Repo reconciled to the golden copy ✅

The Windows repo had drifted from what actually runs. Both files are now corrected:

| File | Was | Now |
|---|---|---|
| `board/esp32s3_st7789.c` | half-step `k_halfstep[8]`, `4096`/`1500 µs`/`4 g`, **bit3=IN1** | full-step `k_fullstep[4] = {0x3,0x6,0xC,0x9}`, `2048`/`3000 µs`/`5 g`, **bit0=IN1** |
| `board/configs/waveshare_lcd/defconfig` | 2,868 B | 2,894 B — added the missing `CONFIG_VELAPAW_FONT_CJK=y` |

The bit-order flip is the one that mattered: the repo's table would have driven the
rotor **backwards**, so food would never have reached the outlet.

**Rule going forward:** the VM board tree is authoritative for `board/`. Anything
edited there gets copied back to `D:` in the same session, or the drift returns.

---

## PHASE 1 — Prove the pipe (go/no-go gate)

**Goal:** speak, hear yourself. Nothing else. No model, no recognition.

### defconfig delta

Verified against `nuttx/arch/xtensa/src/esp32s3/Kconfig`:

```
CONFIG_ESP32S3_I2S=y
CONFIG_ESP32S3_I2S0=y
CONFIG_ESP32S3_I2S0_ROLE_MASTER=y      # required for MCLK
CONFIG_ESP32S3_I2S0_RX=y               # default y
CONFIG_ESP32S3_I2S0_TX=y               # default y
CONFIG_ESP32S3_I2S0_MCLK=y             # default n — MUST enable, codec is dead without it
CONFIG_ESP32S3_I2S0_MCLKPIN=12
CONFIG_ESP32S3_I2S0_BCLKPIN=13         # default 4  ← would collide with LCD CS
CONFIG_ESP32S3_I2S0_DINPIN=14          # default 19 — ASDOUT, codec → ESP (capture)
CONFIG_ESP32S3_I2S0_WSPIN=15           # default 5  ← would collide with LCD SCLK
CONFIG_ESP32S3_I2S0_DOUTPIN=16         # default 18 — DSDIN, ESP → codec (playback)
CONFIG_ESP32S3_I2S0_DATA_BIT_WIDTH_16BIT=y
CONFIG_ESP32S3_I2S0_SAMPLE_RATE=16000  # default 44100; voice only needs 16k

CONFIG_AUDIO=y
CONFIG_DRIVERS_AUDIO=y
CONFIG_AUDIO_ES8311=y
CONFIG_AUDIO_FORMAT_PCM=y
CONFIG_SYSTEM_NXLOOPER=y
```

🔴 **The four pin defaults are the dangerous part.** `BCLKPIN` defaults to 4 (LCD chip
select) and `WSPIN` to 5 (LCD SCLK). Enabling I²S without overriding them will break
the display. Set all five pins explicitly in the same edit that enables I²S.

### Board glue

`nuttx/boards/xtensa/esp32s3/common/src/esp32s3_es8311.c` already exists upstream,
gated on `CONFIG_ESP32S3_I2S && CONFIG_AUDIO_ES8311`. Call
`esp32s3_es8311_initialize()` from board init. No driver to write.

### Test

```
nsh> nxlooper
nxlooper> loopback
```

### Diagnosis table

| Symptom | Cause |
|---|---|
| Your voice, clean | Pipe works. Gate passed. |
| Console dies / no boot | Config landmine — same class as `CONFIG_RTC`. Revert, bisect. |
| Display breaks | I²S pins left at defaults (4/5). Fix `BCLKPIN`/`WSPIN`. |
| Nothing at all | Codec never initialised — I²C address, or MCLK not enabled |
| Silence, no errors | Mic gain at 0 — `ES8311_ADC_REG16` |
| Chipmunk / slow-motion | Sample-rate mismatch codec vs I²S |
| White noise / roar | Wrong bit depth or byte order |
| Choppy | DMA buffers too small |
| Playback OK, capture dead | Codec in DAC-only mode — `audio_mode` not `ES_MODULE_ADC` |

**None of these throw an error.** Your ear is the instrument.

### Order of operations (do not batch)

**Correction, 2026-08-02:** an earlier version of this plan said step 1 was "I²S and
pins only". **That will not link.** `CONFIG_ESP32S3_I2S=y` unconditionally compiles
`boards/xtensa/esp32s3/common/src/esp32s3_board_i2s.c`, and the devkit bringup
unconditionally calls its `board_i2sdev_initialize()`, which calls
`audio_i2s_initialize()`, `audio_register()` and `pcm_decode_initialize()`. Without the
audio framework those are undefined symbols. I²S and the audio core are one step,
whether you want them to be or not.

1. ✅ **DONE 2026-08-02.** **I²S + pins + audio core**, no codec. Boot. **Confirm console
   AND display still work.** This is the step that can break the LCD (pin defaults) and
   the console. Result below.
2. ✅ **DONE 2026-08-02.** **Add `CONFIG_AUDIO_ES8311` + the init call.** Boot. Confirm
   console survives. This is the step that can hang on I²C. Result below.
3. **Assert `PA_CTRL`, then `nxlooper` → `loopback`.** Test with your ears. The speaker
   amp enable is **EXIO7 on the TCA9554**, not a GPIO — `esp32s3_st7789.c` already holds
   the expander handle (`g_ioe`), so this is `IOEXP_SETDIRECTION(g_ioe, 7, OUT)` +
   `IOEXP_WRITEPIN(g_ioe, 7, true)`. Plug the speaker in for this step.

The split that matters is *codec vs no codec* — the codec driver probes I²C at init and
is the part that can hang. Step 1 only brings up a DMA peripheral on five pins that go
nowhere else.

### What step 1 actually needs

```
CONFIG_AUDIO=y
CONFIG_AUDIO_I2S=y            # audio_i2s_initialize()
CONFIG_DRIVERS_AUDIO=y        # note: "menuconfig DRIVERS_AUDIO", drivers/audio/Kconfig
CONFIG_SYSTEM_NXLOOPER=y      # also short-circuits the pcm_decode path in board_i2s.c
```

`CONFIG_AUDIO_FORMAT_PCM` defaults to `y` under `AUDIO`, so it comes free and
`savedefconfig` will strip it. Same for `I2S0_RX`/`I2S0_TX` (default y),
`I2S0_ROLE_MASTER` and `I2S0_DATA_BIT_WIDTH_16BIT` (both choice defaults). Don't be
surprised when they're absent from the file.

`ESP32S3_I2S0` also `select`s `ESP32S3_DMA`, `ESP32S3_GPIO_IRQ` and **`SCHED_HPWORK`** —
a new kernel worker thread with its own stack, on a board where internal RAM is
`CONFIG_RAM_SIZE=114688`. Watch for heap pressure at boot.

### Step 1 RESULT ✅ DONE (2026-08-02) — flashed and verified on hardware

`nuttx.bin` **817,700 B**, only **+1,392 B** over the golden 816,308. That looked wrong
(an I²S driver plus the audio core for 1.4 KB?) so it was checked before spending a
flash cycle — `xtensa-esp32s3-elf-nm nuttx` shows `board_i2sdev_initialize` (420d1e1c),
`audio_i2s_initialize`, `audio_register`, `esp32s3_i2sbus_initialize`, `i2s_send`,
`i2s_receive` all present. The small delta is just `--gc-sections`. **Check the symbol
table, not the binary size.**

| Check | Result |
|---|---|
| Console / CDCACM enumerates after reset | ✅ COM4 (`VID_0525&PID_A4A7`) returns |
| Display renders + touch responds | ✅ "UI is up and very interactive" |
| Recognize still works (heap after `SCHED_HPWORK`) | ✅ unchanged |
| `/dev` audio node present | ✅ `/dev/audio/` → **`pcm0`** (TX) + **`pcm_in0`** (RX) |

`savedefconfig` kept **BCLK=13 / WS=15**; the dangerous Kconfig defaults (BCLK=4 = LCD
CS, WS=5 = LCD SCLK) did not creep back. It also reorders `CONFIG_ESP32S3_I2S=y` to
*after* the `I2S0_*` block — the Windows repo copy was re-sorted to match, byte-identical.

### Step 2 RESULT ✅ DONE (2026-08-02) — flashed and verified on hardware

`nuttx.bin` **884,844 B**, **+67,144 B** over step 1 — a real jump this time, because
`es8311.o` is referenced from bringup and `--gc-sections` can't drop it.

**Code: a new tracked board file, `board/esp32s3_bringup.c`** (4th `cp` line in the
README's deploy block). The devkit bringup has no ES8311 branch, so one was added
mirroring `esp32s3-korvo-2`:

```c
#elif defined(CONFIG_AUDIO_ES8311)
  ret = esp32s3_es8311_initialize(ESP32S3_I2C0, 0x18, 100000, ESP32S3_I2S0);
```

🔴 **It must be `#elif`, never an added call.** `board_i2sdev_initialize()` and
`esp32s3_es8311_initialize()` both register `pcm0` *and* `pcm_in0`; whichever runs
second dies with `-EEXIST`. The generic path is gated only on `CONFIG_AUDIO_CS4344`
upstream, so `CONFIG_AUDIO_ES8311` had to be added to that guard — **and to the
`i2s_enable_tx`/`i2s_enable_rx` declaration guard higher up**, which is the easy half to
miss (korvo-2 does the same at its line 147).

`esp32s3_es8311_initialize()` lives in `boards/xtensa/esp32s3/common/src/`, not korvo-2's
private dir, so it compiles for the devkit with **nothing ported**. `PA_CTRL` is not
touched here — it is EXIO7 on the expander and only matters for playback (step 3).

| Check | Result |
|---|---|
| Console / CDCACM enumerates after reset | ✅ COM4 returns; the I²C probe did **not** hang |
| Codec ACKs on the shared bus | ✅ `[velapaw] ES8311 codec ready on I2C0@0x18 / I2S0` |
| `/dev/audio/` nodes | ✅ `pcm0` + `pcm_in0` |
| Display renders + touch responds | ✅ UI up; `[wslcd] FT6336 id(0xA3)=0x64 ret=0` |
| RTC / camera / stepper unaffected | ✅ `RTC ok`, `OV5640 id=0x5640`, `stepper ready on GPIO 9/10/11/43` |

Two things worth keeping:

- **The node names are the proof.** With the `#elif` taken, `board_i2sdev_initialize()`
  is compiled out entirely — nothing else can register those nodes, so `pcm0`/`pcm_in0`
  existing *is* confirmation that the codec init returned OK.
- **The codec grabs I2C0 first**, ahead of `[wslcd] init` and its expander/touch probes,
  and they still came up clean. That was the whole risk in this step.

### ⚠️ VM-ONLY PATCHES — re-apply after any `repo sync`

None of these live in `contest2026_043_CircuitForge/`, so nothing tracks them.
**`~/fix_vm_patches.sh` applies all six and is idempotent.** (It replaces
`~/fix_hal.sh`, which patched the wrong file: its `grep -rl … | head -1` picked
`modem_clock.c` while the actual failure was in `clk_ctrl_os.c`. The replacement loops
over *every* match.)

🔴 **Ordering: for a config-changing build it is build → fix → build, not fix → build.**
The esp-hal re-clone happens *during* the build, so patching first achieves nothing —
the build replaces the tree, then compiles the unpatched file. A first build failing on
`clk_ctrl_os.c:39 … invalid initializer` is expected; run the script and build again.
Confusingly the script's own output looks correct either way, because it reports on the
tree as it stands *before* the re-clone.

1. **`nuttx/arch/xtensa/src/esp32s3/esp32s3_i2s.c` — add `#include <nuttx/mutex.h>`.**
   Without it: `implicit declaration of nxmutex_lock` at compile, then `undefined
   reference to nxmutex_lock/nxmutex_unlock` at link. `CONFIG_LIBC_SEM_MUTEX_NOINLINE`
   is **off**, so those are `static inline` bodies in the header — there is no exported
   symbol to link against, and an implicit declaration turns them into extern calls.
   Adding the include is the whole fix.
2. **`nuttx/drivers/audio/es8311.c` — the same missing `#include <nuttx/mutex.h>`**
   (`nxmutex_lock` 1318, `nxmutex_unlock` 1383, `nxmutex_init` 2255). Anchor the insert
   on `#include <nuttx/audio/es8311.h>`. This one is an **upstream bug in this
   revision**, not VM/Windows drift — the Windows tree lacks it too.
3. **esp-hal `LOCK_INITIALIZER_UNLOCKED` → `SP_UNLOCKED`** — reverted by the re-clone that
   any Kconfig change triggers. `spinlock_t` is a struct here, so scalar `0` is an
   invalid initializer. Only rewrite the `= 0` form; leave `portMUX_INITIALIZER_UNLOCKED`
   alone.
4. **`nuttx/drivers/audio/es8311.c` — `es8311_configure()` swallows success as `-ERANGE`.**
   Symptom: `loopback` fails with `Error loopback test: 34`. `ret` is pre-loaded with
   `-ERANGE` (lines 1017 / 1064) and the only thing that clears it is
   `ret = es8311_setsamplerate(priv) == -ENOTTY ? OK : ret;` — so a **successful** call
   returning 0 leaves the error in place, because `0 == -ENOTTY` is false. Same bug on
   `es8311_setbitspersample`, in both the INPUT and OUTPUT branches. Upstream bug.
   The sed rewrites all four to `ret = es8311_setX(priv); if (ret == -ENOTTY) ret = OK;`.
   Leave the two bare calls in `es8311_reset()` (≈2191) alone — that path ignores the
   return deliberately.

   ⚠️ Do **not** read the boot-time `MCLK = 4096000 and samplerate = 48000 not supported`
   as the cause. That block is the driver's own init at its 48 kHz default, and
   `{4096000, 16000}` **is** present in `es8311_coeff_div[]` (`es8311.h:543`) — one of ten
   16 kHz entries. At our settings `getcoeff()` succeeds; the fault was purely the ternary.
5. **`apps/system/nxlooper/nxlooper.c:1150` — loop-thread priority 246 → 120.**
   Applied while chasing a console hang blamed on SCHED_FIFO starvation. **It did not fix
   anything** — the hang was `CONFIG_DEBUG_AUDIO_INFO` logging in the per-buffer path.
   Harmless, but revert it if you ever want a clean diff against upstream.
6. **`apps/system/nxlooper/nxlooper.c:476` — start the play device before the record
   device.** The real capture fix; see "ROOT CAUSE" below. Without it RX waits for a
   BCLK that only the TX module can generate, and `loopback` hangs forever.

## Step 3 IN PROGRESS — PA_CTRL + the `nxlooper` ear test

**`PA_CTRL` is done.** The NS4150B enable is **TCA9554 EXIO7, not a GPIO**, so the ES8311
driver cannot reach it. `board_speaker_enable(bool)` was added to `esp32s3_st7789.c`
(next to the existing `g_ioe` handle) and is asserted at boot under
`#ifdef CONFIG_AUDIO_ES8311`. Confirmed on hardware:
`[velapaw] speaker amp enabled (PA_CTRL = EXIO7)`. It is exported rather than inlined so
the app can gate the amp per-playback later — leaving it on idles the amp and can hiss.

**🔴 `nxlooper` cannot allocate buffers unless `CONFIG_AUDIO_DRIVER_SPECIFIC_BUFFERS=y`.**
Symptom: `loopback` returns to the prompt with no error, nothing is audible, and `dmesg`
shows `nxlooper_loopthread: ERROR: Could not allocate buffer 0` — the loop thread tears
down immediately, so **nothing ever reaches the codec** and neither the amp nor the mic
is implicated. The chain:

1. nxlooper issues `AUDIOIOC_GETBUFFERINFO`; es8311 answers `Unhandled ioctl: 4106`.
2. `audio.c:1267` sets `upper->nbuffers` **only** when the lower half answers that ioctl
   successfully, so it stays 0 from the zalloc.
3. `audio_allocbuffer()` (`audio.c:786`) opens with
   `if (upper->periods >= upper->nbuffers) return 0;` → `0 >= 0` → returns 0.
4. nxlooper requires `ret == sizeof(buf_desc)`, sees 0, and errors out.

It is **not** memory pressure — the allocator refuses before it ever tries. es8311
already implements the handler at `es8311.c:1806`; the whole `case` is wrapped in
`#ifdef CONFIG_AUDIO_DRIVER_SPECIFIC_BUFFERS`. Upstream Kconfig miss: `AUDIO_ES8388`
carries `select AUDIO_DRIVER_SPECIFIC_BUFFERS`, `AUDIO_ES8311` does not, even though
`ES8311_BUFFER_SIZE`/`ES8311_NUM_BUFFERS` are defined unconditionally. **Fix is one
defconfig line, no source patch.** Gives 4 × 8 KB per direction = 64 KB, and at 16 kHz
mono ≈256 ms per buffer, so the ear test will echo about a second late. That is expected.

**Debug-only defconfig entries to back out before shipping:** `CONFIG_DEBUG_AUDIO`,
`CONFIG_DEBUG_AUDIO_ERROR`, `CONFIG_DEBUG_AUDIO_INFO`, `CONFIG_DEBUG_AUDIO_WARN`,
`CONFIG_DEBUG_FEATURES`, `CONFIG_RAMLOG_BUFSIZE=16384`.

### Reading the RAMLOG

**`dmesg` does not drain the buffer, and a full buffer drops new messages.** The 1024 B
default filled during boot with `DEBUG_AUDIO_INFO` on, so every post-boot message was
discarded and three consecutive `dmesg` runs returned byte-identical boot text — which
reads exactly like "nothing is happening" when in fact nothing was being *recorded*.
`CONFIG_RAMLOG_BUFSIZE=16384` fixes it; RAMLOG lives in `.bss` so `nuttx.bin` is unchanged.

NSH has **no pipe** and its `dmesg` takes **no arguments** — `dmesg | grep es8311` gives
"too many arguments". `dmesg` is also not an `nxlooper` command; type it at `nsh>` only.
Prefer `q` over `stop` to end a loopback: `quit` stops the loop itself, so it is one
blocking call rather than two.

### Console: use miniterm, not a script

`py -m serial.tools.miniterm COM4 115200` (Windows, own terminal; quit Ctrl-]) gives a
working `nsh>` immediately. Driving COM4 from a `System.IO.Ports.SerialPort` script gets
**character echo but never a prompt or command output**, on CR/LF/CRLF alike — NuttX
echoes in the driver receive path with or without a reader, so echo is not evidence the
shell is listening. Don't repeat that diagnosis; just use miniterm.

### 🔴 ROOT CAUSE — capture never completes because `nxlooper` starts RX before TX

Symptom: `loopback 1 16 16000` allocates and configures cleanly, one thump comes out of
the speaker, then **nothing**, and `q` hangs. `nxlooper_stop()` joins the loop thread,
which is parked in `mq_receive` (`nxlooper.c:508`) waiting for a buffer that never
returns — so the record side never delivered a single buffer.

It is not MCLK, and it is not a pin swap:

- `arch/xtensa/src/esp32s3/Kconfig` — `choice "I2S0 role" default ESP32S3_I2S0_ROLE_MASTER`,
  and `ESP32S3_I2S0_MCLK` **depends on** `ESP32S3_I2S0_ROLE_MASTER`. Our defconfig has
  `CONFIG_ESP32S3_I2S0_MCLK=y`, so master role is necessarily active and MCLK is driven
  on GPIO12. The "slave role never configures MCLK" hypothesis is dead.
- `velapaw-hardware.md` — IO14 is the codec's ASDOUT (codec → ESP, our `DINPIN=14`) and
  IO16 is DSDIN (ESP → codec, our `DOUTPIN=16`). The defconfig matches the schematic.

The actual chain:

1. `esp32s3_es8311.c:142/188` creates **two** es8311 instances (`/dev/audio/pcm0` out,
   `/dev/audio/pcm_in0` in) that **share one `esp32s3_i2sbus_initialize(0)` instance** —
   one `priv`, one `priv->rate`, one `priv->data_width`, one clock.
2. Because that instance has both `tx_en` and `rx_en`, `esp32s3_i2s.c:1503-1506` sets
   **`I2S_SIG_LOOPBACK`** in `I2S_TX_CONF_REG`: in full duplex the **TX module is the
   clock master and RX shares its BCLK/WS**.
3. `i2s_rx_channel_start()` (`esp32s3_i2s.c:2145-2194`) only resets DMA/RX/FIFO, sets
   `I2S_RX_UPDATE` and enables the IRQ — it **never sources a bit clock of its own**.
   With TX idle there is no BCLK/WS, so RX shifts in nothing and no DMA EOF ever fires.
4. `nxlooper_loopthread` starts the **record** device first (`nxlooper.c:476-489`) and
   issues `AUDIOIOC_START` on the **play** device only inside the `AUDIO_MSG_DEQUEUE`
   handler (`nxlooper.c:576-588`) — i.e. after the first record buffer comes back.

RX waits on TX; TX waits on RX. **Deadlock by construction.** The single thump is the
play node's configure sequence (`i2s_txdatawidth`/`i2s_txsamplerate` each stop/start the
TX channel) clicking the DAC once — proving the output path, amp and speaker are fine.

**Attempted fix (VM patch #6):** start the play device up front, before the record start,
and set `loopstate = NXLOOPER_STATE_LOOPING` so the deferred start at 576 is skipped.

⚠️ **Patch #6 alone is NOT sufficient — the last assumption in it is wrong.** Instrumented
run (`VP:` probes) printed `play started ret=0` and `record started, entering loop`, then
**zero messages**. `AUDIOIOC_START` on the play node does not start the I²S TX *hardware*:
`es8311_start()` only writes codec registers and spawns the worker thread, and
`es8311_processbegin()` finds `pendq` empty so it issues no `I2S_SEND`.

`I2S_TX_START` is set in exactly one place — `esp32s3_i2s.c:709`, inside the DMA setup
that pops a buffer off `priv->tx.pend`. **Submitting a buffer is what starts the clock.**
`I2S_RX_START` is likewise set only at `:771`. So RX is armed and started but, with
`I2S_SIG_LOOPBACK` sourcing its BCLK/WS from an idle TX module, it never shifts a bit —
no EOF, no DMA interrupt, no `AUDIO_MSG_DEQUEUE`, `mq_receive` blocks forever.

**Fix (VM patch #7):** before the play `AUDIOIOC_START`, take one buffer off `playdq`,
zero it, and `nxlooper_enqueueplaybuffer()` it. Enqueueing before start is the driver's
own documented "priming the pump" path (`es8311.c:1732-1736` — with `priv->mq` still
NULL the buffer just lands on `pendq`). The subsequent start then drains it through
`I2S_SEND` → `i2s_txdma_setup` → `I2S_TX_START`, and BCLK/WS finally run.

### 🔴 SECOND BUG — `CONFIG_I2S_DMADESC_NUM=2` is two bytes too small for the ES8311

With patch #7 in, the prime finally reached the I²S layer and failed loudly:
`es8311_processbegin: I2S transfer failed: -27` (`-EFBIG`).

`i2s_send()` rejects any transfer larger than `ESP32S3_DMA_BUFLEN_MAX * I2S_DMADESC_NUM`
(`esp32s3_i2s.c:2772`):

| symbol | value | where |
|---|---|---|
| `ESP32S3_DMA_BUFLEN_MAX` | `0x1000 - 1` = **4095** | `esp32s3_dma.h:59,67` |
| `CONFIG_I2S_DMADESC_NUM` | default **2** | `arch/xtensa/src/esp32s3/Kconfig:576` |
| ceiling | 4095 × 2 = **8190** | |
| `CONFIG_ES8311_BUFFER_SIZE` | **8192** | `include/nuttx/audio/es8311.h` |

**Over by 2 bytes.** RX never hit it because `i2s_receive()` silently clamps with
`MIN(nbytes, ESP32S3_DMA_BUFLEN_MAX)` (`:2880`); only the TX path errors out. This is
**not** specific to the priming buffer — `nxlooper.c:570` sets `apb->nbytes =
apb->nmaxbytes` on every play buffer, so playback would have failed the same way. The
es8311 driver's preferred buffer size and the ESP32-S3 I²S DMA defaults are simply
incompatible as shipped.

**Fix:** `CONFIG_I2S_DMADESC_NUM=4` in the defconfig → ceiling 16380. Costs one extra
`esp32s3_dmadesc_s` array per buffer container; negligible RAM. No source patch.

⚠️ This is a **config** change, so it triggers the esp-hal re-clone — follow the
**build → fix → build** rule above (first build may fail on `clk_ctrl_os.c`; run
`~/fix_vm_patches.sh`, then build again).

### RESULT of the DMADESC=4 build (2026-08-03) — TX clock CONFIRMED, RX still silent

Flashed `nuttx-dmadesc.bin` (887,520 B, md5 `d2fe3e3307e39d0265a3af557cd2044d`).
Console:

```
nxlooper_loopthread: VP: primed TX with silence ret=0
nxlooper_loopthread: VP: play started ret=0
nxlooper_loopthread: VP: record started, entering loop
nxlooper_loopthread: VP: msg size=8 id=1
nxlooper_loopthread: VP: deq apb=0x3c4c5d70
nxlooper_loopthread: VP: deq flags=24 nbytes=0 nmax=8192
```

**What this proves (both root causes above were real and are fixed):**

* No `-27`. `CONFIG_I2S_DMADESC_NUM=4` lifted the ceiling to 16380 and the 8192-byte
  buffer went through — the second bug is closed.
* `flags=0x24` = `AUDIO_APB_PLAY (1<<5)` | `AUDIO_APB_DEQUEUED (1<<2)`
  (`nxlooper.c:57-58`, `audio.h:529`). That is the **primed silence buffer coming
  back**. A TX DMA transfer ran start to finish, which means `i2s_txdma_start()`
  reached `modifyreg32(I2S_TX_CONF_REG, 0, I2S_TX_START)` at `esp32s3_i2s.c:709` and
  **BCLK/WS actually ran**. The first root cause is closed too.
* The clock does **not** stop afterwards: `I2S_TX_START` is only ever cleared in
  `i2s_tx_channel_stop()` (`:2225`), which nothing calls here. BCLK free-runs.

**What is still broken:** the record node never returns a single buffer. Exactly one
message arrived — the TX one — and then nothing. `nxlooper`'s dequeue handler only
copies/re-feeds when `dq_count(&playdq) != 0 && dq_count(&recorddq) != 0`
(`nxlooper.c:543`), so with `recorddq` permanently empty the loop is idle by
construction, not stuck.

So RX has a free-running bit clock and still never reaches a `suc_eof`. It should
fire after `MIN(8192, 4095)` = **4095 bytes ≈ 128 ms** (`i2s_rxdma_start`,
`:763-766`) — well inside the 256 ms the primed TX buffer covered.

**Ruled out at source level (do not re-investigate):**

* TX/RX IRQs are *not* aliased — `ESP32S3_PERIPH_DMA_OUT_CH0 + ch` and
  `ESP32S3_PERIPH_DMA_IN_CH0 + ch` are distinct sources, each with its own
  `esp32s3_setup_irq` + `irq_attach` (`:3075-3119`).
* The RX submit path is complete and correct: `i2s_receive` → `esp32s3_dma_setup` →
  `sq_addlast(rx.pend)` → `i2s_rxdma_start` → in-link load, `DMA_IN` enable,
  `I2S_RX_START` (`:940-978`, `:736-776`).
* `i2s_rx_schedule` moves `rx.act` → `rx.done` and re-arms (`:1100-1160`).

**The one unknown left is whether `I2S_RECEIVE` is ever called at all** — i.e. whether
the record node's `es8311_processbegin` takes the ADC branch. There is no probe on the
record side; `auderr("I2S transfer failed")` only prints on a *failed* call, so
"never called" and "called and returned OK" are indistinguishable from this output.
Next diagnostic (cheap, one build): `auderr` in `es8311_processbegin` printing
`priv->audio_mode` and the branch taken, plus one at the top of `i2s_receive`.

### 🔴 FOURTH BUG — **THE RX STALL**: `I2S_RX_EOF_NUM` is set to an odd byte count

Probe build `nuttx-probe2.bin` (887,592 B, md5 `da85e6f62103661511cb8cf2d63ec267`) settled it:

```
VP: primed TX with silence ret=0
VP: pb mode=2 n=8192          <- play node, ES_MODULE_DAC  (I2S_SEND)
VP: play started ret=0
VP: pb mode=1 n=8192          <- record node, ES_MODULE_ADC (I2S_RECEIVE)
VP: i2s_receive rx_en=1
VP: pb mode=1 n=8192
VP: i2s_receive rx_en=1
VP: record started, entering loop
VP: msg size=8 id=1 / deq flags=24     <- only the TX buffer ever returns
```

(`es_module_t`: ADC=1, DAC=2, ADC_DAC=3.) So both nodes have the **correct** direction,
`rx_en` is true, and RX buffers really are reaching the lower half. `VP: rx_worker fired`
**never** appears — the RX DMA is armed and never completes.

**Cause**, `esp32s3_i2s.c:2876-2880`:

```c
nbytes = apb->nmaxbytes;                        /* 8192 */
nbytes -= (nbytes % (priv->data_width / 8));    /* 8192 % 2 == 0 -- no change */
nbytes = MIN(nbytes, ESP32S3_DMA_BUFLEN_MAX);   /* -> 4095   ODD */
```

The alignment runs **before** the clamp, so the clamp destroys it. 4095 propagates into
`i2s_rxdma_start` (`:763-766`) and is written to `I2S_RX_EOF_NUM`. The RX module fills
the DMA in 32-bit FIFO words, so its received-byte counter advances 4 at a time —
0, 4, … 4092, 4096 — and **never equals 4095**. `in_suc_eof` never fires,
`i2s_rx_schedule` is never called, `i2s_rx_worker` never runs. Capture stalls forever.

TX is immune: its EOF comes from the descriptor chain, not a byte-count register.
ESP-IDF avoids this by 4-byte-aligning `dma.buf_size` before
`i2s_ll_rx_set_eof_num()`. Same family as the DMADESC bug — `ESP32S3_DMA_BUFLEN_MAX`
is a descriptor-sizing maximum being used as a word-aligned hardware threshold.

**VM patch #9:** re-align after the clamp — `nbytes &= ~UINT32_C(3);` → 4092, which is
divisible by 2, 3 and 4, so 16/24/32-bit widths are all safe.

### ✅ Patch #9 CONFIRMED on hardware — and two more bugs behind it

Build `nuttx-eofalign.bin` (887,592 B, md5 `35eea0c23b622ad99fb975aa624f95b6`):

```
VP: record started, entering loop
VP: rx_worker fired                    <- NEW.  RX completes.  Patch #9 was correct.
VP: pb mode=1 n=8192
VP: i2s_receive rx_en=1
VP: msg size=8 id=1
VP: deq flags=1c nbytes=0 nmax=8192    <- record buffer: RECORD|FINAL|DEQUEUED, EMPTY
VP: msg size=8 id=1
VP: deq flags=24 nbytes=0 nmax=8192    <- play buffer
```

`I2S_RX_EOF_NUM` was the stall. Two further defects are now visible:

#### 🔴 FIFTH BUG — RX length sum can't handle a multi-descriptor chain

`i2s_rx_worker` (`esp32s3_i2s.c:1292-1300`):

```c
while (dmadesc != NULL && (dmadesc->ctrl & ESP32S3_DMA_CTRL_EOF))
  { apb->nbytes += DATALEN(dmadesc); dmadesc = dmadesc->next; }
```

`esp32s3_dma_setup` sets `suc_eof` **in software only for TX** (`esp32s3_dma.c:324-331`);
for RX the hardware sets it, and only on the **last** descriptor. So on any chain longer
than one the test fails at descriptor 0 and `nbytes` stays 0.

It is always longer than one here: `esp32s3_dma.c:248` checks `esp32s3_ptr_extram()`, and
with `CONFIG_ESP32S3_SPIRAM=y` the 8 KB audio buffers are in PSRAM, so `dma_size` becomes
`0x1000 - alignment` (4080 for 16-byte blocks) and 4092 bytes splits in two.

**VM patch #10:** sum every descriptor, `break` *after* the one carrying EOF.

#### 🔴 SIXTH BUG — `AUDIO_APB_FINAL` on every captured buffer kills the record worker

`i2s_rx_worker:1306-1309` stamps `AUDIO_APB_FINAL` whenever `priv->streaming == false`.
`priv->streaming` is only ever set by `I2S_IOCTL(AUDIOIOC_START)` (`:2966-2972`) — and
**`es8311.c` contains no `I2S_IOCTL` call at all**, so it is false forever.

`es8311_returnbuffers` (`es8311.c:1248-1262`) reads `AUDIO_APB_FINAL` as end-of-stream and
sets `priv->terminating = true`, so the record worker exits after **one** buffer. That is
exactly the single record dequeue in the log above.

**VM patch #11:** set `priv->streaming = true` in `i2s_receive` when a transfer is queued.
⚠️ The upstream-correct fix is for `es8311_start`/`es8311_stop` to forward
`AUDIOIOC_START`/`AUDIOIOC_STOP` down via `I2S_IOCTL`; patch #11 is the low-risk local
equivalent, chosen because the VM's `es8311.c` already carries the `-ERANGE` fix and its
text differs from the D: copy. Revisit if this is ever sent upstream.

### 🔴 SEVENTH BUG — nxlooper's copy path underflows (crash, 2026-08-03)

Build with patches #10 + #11 (887,592 B, md5 `e8f4b6528a73f8c1db165c9b3dd4ec34`) panics:

```
es8311_setsamplerate: Failed to set sample rate: -22   (x2, benign)
xtensa_user_panic: User Exception: EXCCAUSE=001c task: nxlooper
```

`EXCCAUSE=0x1c` is Xtensa **LoadProhibited** — a load from an unmapped address.

⚠️ **Do not read the missing `VP:` lines as "it crashed early".** `CONFIG_SYSLOG_BUFFER=y`
means syslog passes through an intermediate buffer whose tail is lost on panic. The probes
almost certainly ran.

Both new patches were cleared by inspection:

* **Patch #11 is inert.** A grep shows `priv->streaming` is read in exactly ONE place,
  `esp32s3_i2s.c:1306`. It can only suppress `AUDIO_APB_FINAL`; it cannot fault.
* **Patch #10 does not walk off the chain.** `esp32s3_dma.c:313` sets
  `dmadesc[i].next = &dmadesc[i + 1]` in the loop, but `:316-319` breaks once `bytes == 0`
  and `:333` then writes `dmadesc[i].next = NULL`. At 4092 bytes with `dma_size` 4080 the
  chain is exactly 2 descriptors and is properly NULL-terminated.

**Cause: the patches worked, and that woke up dead code.** Until now the record worker died
after one buffer, so `dq_count(&playdq) != 0 && dq_count(&recorddq) != 0`
(`nxlooper.c:543`) was never both-true. Patch #11 keeps the recorder alive and patch #10
gives it a real `nbytes`, so the copy body below now executes — in nxlooper's own task,
which is the task the panic names. `nxlooper.c:551-555`:

```c
copy = MIN(apbrec->nbytes - apbrec->curbyte,
           apb->nmaxbytes - apb->curbyte);
memcpy(apb->samp + apb->curbyte, apbrec->samp + apbrec->curbyte, copy);
```

`nbytes` and `curbyte` are unsigned. `apbrec` is a `dq_peek` (`:548`), so it can be a
partially-consumed buffer carrying a non-zero `curbyte` while a requeue writes a smaller
`nbytes` — the subtraction wraps to ~4 G and `memcpy` leaves the buffer.

**VM patch #12:** print all four operands plus both `samp` pointers, and clamp `copy` to 0
on a bad state. Note the guard converts the panic into a *spin* (`:559`'s
`curbyte == nbytes` never advances), which is intentional — a hang preserves console
output, a panic eats it. Expect to need RESET rather than `q`.

## ⛔ RETRACTED: "every audio test must start from a cold boot" ⛔

**This rule was wrong and has been withdrawn (2026-08-03, later the same day).** Cold-booting
is still harmless and still worth doing for consistency, but it does **not** prevent the
`EXCCAUSE=001c` panic and must not be treated as a precondition for a valid test.

### How the retraction was established

The original rule rested on a single control experiment (n = 1 warm panic, n = 1 cold clean).
Two further binaries were then cold-booted:

| Binary | Delta | Cold-boot result |
|---|---|---|
| `nuttx-cpguard.bin` | #9–#12 | clean (the original n=1) |
| `nuttx-rxreset2.bin` | +#15 | clean |
| `nuttx-txstop.bin` | −#15, +#16 | **panic ×2** |
| `nuttx-cpguard.bin` (re-flashed as control) | #9–#12 | **panic** |

The last row is decisive: the *same* binary that cold-booted clean also cold-booted into the
panic. The fault is **intermittent regardless of boot state**, and the two clean runs were
luck. Consequences:

* **Patch #16 is exonerated** — it was suspected only because the panic followed it.
* A single clean run proves nothing. **Any claim that a change fixed or caused the panic
  needs repeated runs**, because the base rate of the fault is high but not 100 %.
* The "stale ES8311 register state" explanation below is **not supported** by the evidence
  and should be treated as an open question, not a finding.

### The superseded reasoning (kept for the retractions it contains)

Five consecutive `EXCCAUSE=001c` panics were blamed, in turn, on patch #13's probes, patch
#14's probes and patch #15's RX reset. Then the known-good patch-12 binary was reflashed as
a control:

```
nuttx-cpguard.bin  887,688 B  md5 2c77c9b50ca3b4e4a477c560998acd40
```

That is the *exact* binary that had earlier produced `VP: cp copy=4092` with no panic — and
it panicked too. After a full USB power-cycle the same binary ran clean.

**Retractions — these earlier conclusions were wrong:**

* Patches **#13, #14 and #15 did NOT cause any panic.** All three remain **untested**.
  (This retraction still stands.)
* ~~The `EXCCAUSE=0x1c` panic is **stale ES8311 register state after a soft reset**, not a
  code defect in any recent patch.~~ — **itself retracted, see the table above.** The panic
  is not code-defect-free and is not explained by soft-reset state; it is an unexplained
  intermittent LoadProhibited in nxlooper's setup path, and it is still open.
* **Never localise a fault by absence of console output.** This console is USB CDC-ACM
  (`VID_0525&PID_A4A7`); on panic the queued IN endpoints are never serviced and the tail is
  discarded. That is also why no stack dump ever appears — it is not a locked UART and not
  a faulting panic handler.

### Also ruled out by inspection during this hunt

* **The `-22` sample-rate errors are benign.** `MCLK = 4096000` is 256 × 16000, which proves
  the 16 kHz request *did* reach the driver; the failing call is a separate configure at the
  codec's default 48 kHz. The same two `-22` pairs appear in runs that go on to work, and
  `es8311.c:687-691` returns before touching any I²S call, so it cannot leave state
  half-initialised. Do not "fix" this.
* **Patch #7 (TX priming) is clean.** `es8311_enqueuebuffer` guards the message send with
  `if (priv->mq.f_inode != NULL)` (`es8311.c:1739`), so enqueueing before start really does
  just land on `pendq`.

⚠️ **Instrumentation hazard:** `syslog()` in ISR context dispatches through the syslog
channel's `sc_force` method, which CDCACM does not provide — the NULL call faults with
`EXCCAUSE=0x14` (InstrFetchProhibited). `i2s_rx_schedule` is called *from*
`i2s_rx_interrupt`, so it counts as ISR context. Never put `syslog` there. Record into a
static and print from thread context.

### Confirmed cold-boot baseline (control build, patches #9–#12, no #15)

```
VP: primed TX with silence ret=0
VP: pb mode=2 n=8192 / VP: play started ret=0
VP: pb mode=1 n=8192 / VP: i2s_receive rx_en=1     (x2)
VP: record started, entering loop
VP: deq flags=24 nbytes=0 nmax=8192                 <- only the primed TX buffer returns
```

No `VP: rx_worker fired`. **The RX stall is real and reproducible from cold** — which is
what patch #15 targets.

### 🔴 THIRD BUG (found by inspection 2026-08-03, not yet the cause of the RX stall)

`/dev/audio/pcm0` and `/dev/audio/pcm_in0` are two separate `es8311_dev_s` instances
driving **one physical codec** over I²C. `nxlooper` configures record first
(`AUDIO_TYPE_INPUT`, `nxlooper.c:1077-1084`) then play (`AUDIO_TYPE_OUTPUT`, `:1095-1097`).

`es8311_configure` calls `es8311_reset(priv)` in **both** cases, and `es8311_reset`
writes `ES8311_RESET_REG00 = 0x80` (`es8311.c:2169`) — "puts all ES8311 registers back
in their default state". Then `es8311_setbitspersample` programs only the path matching
that instance's `audio_mode`:

* ADC → `ES8311_SDPOUT_REG0A` (`:633-639`)
* DAC → `ES8311_SDPIN_REG09` (`:641-647`)

So the play node's reset **wipes the REG0A word length the record node just programmed**,
and nothing reprograms it. The mic runs at the codec's power-on default format.

This produces garbage/silent capture, **not** a missing `suc_eof` — so it is not the
current stall. But it will bite immediately once the stall is fixed.

**Planned fix (VM patch #8, NOT yet applied):** in the `AUDIO_TYPE_OUTPUT` case, set
`priv->audio_mode = ES_MODULE_ADC_DAC` across `es8311_reset` +
`es8311_setsamplerate` + `es8311_setbitspersample`, then restore `ES_MODULE_DAC` before
returning — the restore is mandatory, otherwise `es8311_processbegin` (`:1365`) would
take the `I2S_RECEIVE` branch for the playback node. Note the record node's
`es8311_start` re-enables the ADC (`:1425-1433`) and, with VM patch #6, record starts
*after* play, so the ordering works in our favour.

⚠️ The VM's `es8311_configure` already carries the `-ERANGE` fix, so its text around
`:1037-1051` differs from the D: copy — check the anchor before scripting this one.

### Ruled out (do not re-investigate)

* Record node is **not** stuck in DAC mode — it is configured `AUDIO_TYPE_INPUT`, which
  calls `es8311_audio_input()` → `audio_mode = ES_MODULE_ADC` (`:1084`, `:1971`).
  The two `es8311_setsamplerate: -22` pairs at loopback time are the two `es8311_reset()`
  calls, one per node, which is positive proof both configures ran.
* `CONFIG_AUDIO_I2S` does **not** guard the direction branch — `es8311_processbegin` is
  unconditional. Our `es8311_processbegin` takes **one** argument
  (`FAR struct es8311_dev_s *priv`), has no `type`/`apb` parameter and no
  `AUDIO_TYPE_RECORD` dispatch; `I2S_RECEIVE` takes **five** args with callback
  `es8311_processdone`. Advice written against the other, multi-arg variant of this
  driver does not apply here.

### ABORT CRITERIA

If Phase 1 is not passing after **~2 working sessions**, stop and reflash the golden
binary. Voice control is a stretch feature; the enclosure assembly and the open JLC
reorders are committed deliverables and outrank it.

---

## PHASE 1.5 — Borrow TFLM's micro_speech (do this before collecting any data)

Found 2026-08-02: the vendored tflite-micro tree already contains a complete,
**pre-trained** keyword-spotting example. Nothing to train, nothing to record.

```
apps/mlearning/tflite-micro/tflite-micro/tensorflow/lite/micro/
  examples/micro_speech/models/micro_speech_quantized.tflite    18,800 B  yes/no/silence/unknown
  examples/micro_speech/models/audio_preprocessor_int8.tflite    8,772 B  MFCC frontend, as a graph
  models/keyword_scrambled_8bit.tflite                          29,632 B  second KWS model
```

Two things this changes:

1. **The feature frontend is a tflite graph, not code you write.** Phase 3 originally
   assumed hand-rolling MFCC against `CONFIG_MATH_KISSFFT`. Invoking
   `audio_preprocessor_int8.tflite` instead removes that code entirely *and* removes
   the classic KWS failure mode — host-side and device-side features diverging, which
   shows up as a model that scores 95 % in training and 40 % on the board, with nothing
   to debug because both halves "work".
2. **You can prove the whole chain before investing in a dataset.** 18.8 KB is inside
   the arena budget Phase 4 assumes. Wire it up, say "yes" at the board, and if it
   lands then I²S capture → preprocessing → third interpreter → result is all verified.

**Gate:** the board recognises "yes" and "no" spoken at the enclosure. Only then start
Phase 2. If this doesn't pass, the fault is in the pipe, not in your data — and finding
that out now costs a day instead of a fortnight.

⚠️ `micro_speech` is trained at 16 kHz mono, which matches the Phase 1 I²S settings.
Keep them aligned; a sample-rate mismatch here degrades accuracy silently rather than
erroring.

## PHASE 2 — Dataset  *(REVISED 2026-08-05 — no recording session)*

**This phase originally specified recording ~10–15 words yourself**, through this mic,
in the printed enclosure, with the stepper running, and rated the outcome *"roughly a
coin flip"* against the schedule. That risk was priced against building a dataset from
scratch. It turns out not to be necessary, and the paragraphs below supersede it.

**Google Speech Commands v0.02** (Warden 2018 — 105,829 one-second 16 kHz clips,
2,618 speakers, 35 words, CC BY 4.0) already contains every word the scheduling dialog
needs. The vocabulary was chosen to fit the dataset rather than the other way round:

| dialog step | words | in dataset |
|---|---|---|
| meal slot | `one` `two` `three` | ✅ (reuses the digits) |
| hour | `zero`–`nine` | ✅ |
| confirm | `yes` `no` | ✅ — *already shipping on the board* |
| **pet** | — | **never spoken; the camera already identifies the pet** |

The words the dataset *lacks* — "schedule", "breakfast", a wake word — are exactly the
ones a button and three numbered meal slots replace at no cost. See
[PHASE 5](#phase-5--wire-to-the-ui) for what that costs the UX.

This is not a new dependency either: `micro_speech`, the model Phase 1.5 already put on
the board at yes 0.980 / no 0.789 live, was trained on this same dataset. **The domain
gap between crowdsourced laptop audio and an ES8311 in a printed enclosure is therefore
measured on this hardware, not hypothetical** — and it is survivable.

Custom recording is not deleted, only demoted: it becomes *fine-tuning on top of a
working model* if the digits underperform on-device for accent reasons. That is hours
of work from a good starting point, not a fortnight from zero.

## PHASE 3 — Train (host side)  *(REVISED 2026-08-05)*

Built and documented at **`host/kws/`** — see `host/kws/README.md` for the full recipe.

Architecture is **`tiny_conv` retrained at 14 labels**, not DS-CNN-S. Retraining
`micro_speech`'s own architecture keeps the input shape, the preprocessor graph, and the
op set identical to what Phase 1.5 already proved on this board; the only thing that
changes is the number of output classes. DS-CNN-S would be smaller at 14 labels
(~38.6 KB vs ~50 KB, because global average pooling collapses the head) but needs
`DEPTHWISE_CONV_2D` + `AVERAGE_POOL_2D` added to the resolver and re-proves nothing.
~11 KB is not worth spending a bring-up on when 5 MB of flash is unallocated.

**Label order is load-bearing.** `input_data.prepare_words_list()` returns
`[_silence_, _unknown_] + wanted_words`, so putting `yes,no` first *extends* the device
enum instead of renumbering it:

```
 0 _silence_   1 _unknown_   2 yes     3 no
 4 zero   5 one   6 two   7 three   8 four
 9 five  10 six  11 seven 12 eight  13 nine
```

`VELAPAW_KWS_YES = 2` and `NO = 3` stay valid, so build 54's code keeps working.
Reordering `WORDS` without editing `kws.h` makes the board confidently report the wrong
word with nothing in the logs to explain it.

The ~23 dataset words we don't ask for fold into `_unknown_` automatically — free
negative training data, which is the main reason a public dataset beats a hand-recorded
one at this vocabulary size.

Feature geometry is asserted equal to the board (49 frames × 40 bins = 1960, 16 kHz,
30 ms window / 20 ms stride); `PREPROCESS='micro'` is the same `audio_microfrontend`
algorithm `audio_preprocessor_int8.tflite` implements on-device. Training is CPU-only —
TF dropped native Windows GPU after 2.10 and this venv has the `tensorflow-intel` wheel.
18,000 steps is an overnight job.

**Gate:** int8 test accuracy ≥ 90 % → proceed; 85–90 % → usable, expect more "say
again"; < 85 % → stop before spending device time. Expect the digits below yes/no —
`three`/`free` and `nine`/`five` are genuinely close.

### Result — 2026-08-05: PASSED, on the metric that matters

18,000 steps, 84.2 % validation. Test split n=5623: **float 80.90 %, int8 80.85 %**,
model 59,024 B. Under the gate line above — and the gate line was measuring the wrong
thing. The deficit is nearly all `_unknown_` at 34.1 %, a class the product never names.

VelaPaw never makes a 14-way decision; each dialog step knows its legal answers, so
argmax restricted to that subset is the real number:

| step | int8 | with a raw-probability threshold |
|---|---:|---|
| MEAL 3-way | **95.68 %** | p ≥ 0.45 → accept 74.8 %, correct **99.24 %** |
| HOUR 10-way | **84.95 %** | p ≥ 0.73 → accept 64.6 %, correct **96.87 %** |
| CONFIRM 2-way | **97.45 %** | p ≥ 0.59 → accept 80.7 %, correct **99.55 %** |

🔴 **Threshold on the raw softmax probability of the best legal word, not on a
confidence renormalised over the legal subset.** Renormalising discards the probability
mass on `_unknown_` — precisely the mass that means "not one of my words" — and lets
**86 % of silence/OOV clips through at CONFIRM** versus 4.9 % for the raw test at a
comparable accept rate. This is a device-code decision, not an analysis detail.

End to end, three tries per step: a wrong time reaches the confirm screen 3.7 % of the
time and the owner rejects it there, so a **wrong feeding time is saved in 0.017 % of
dialogs**; 6.0 % of dialogs are abandoned after three tries (HOUR's threshold is the
dial). Full derivation and the per-word confusion table in `host/kws/README.md`.

These are laptop-mic clips — on-board figures through the ES8311 will be lower, so
re-tune the three thresholds on hardware.

## PHASE 4 — On device  *(BUILT in b54; REVISED 2026-08-05 for 14 labels)*

Already done — `app/velapaw/voice/kws.cc` runs the third and fourth interpreters
(frontend + classifier) with their own arenas, exactly the `backend_tflm.cc` pattern.
Actual numbers, not the estimates this section used to carry:

| | planned | as built |
|---|---|---|
| classifier arena | ~30 KB | `KWS_CLASSIFIER_ARENA` **8 KB** |
| frontend arena | — | `KWS_FRONTEND_ARENA` **12 KB** |
| classifier resolver | `<8>` | `MicroMutableOpResolver<4>` (**`AddConv2D`**, not depthwise, from b55) |
| frontend resolver | — | `MicroMutableOpResolver<18>` |

**Embed the model in rodata**, do not flash-load it — it rides inside `nuttx.bin` as a
`const uint8_t[]`, no flash offset, no `esptool` line, no cache-suspend `.bss`-stack
thread. Simplest of the four models by far.

```bash
python3 host/gen_model_data.py --input host/kws/models/kws_int8.tflite \
    --symbol g_micro_speech_quantized_model_data --outdir app/velapaw/voice/gen
```

What the 14-label model changes — **as done in b55**, two items differing from what this
section predicted:

1. `voice/kws.h` — `VELAPAW_KWS_CATEGORIES` 4 → 14, `ZERO`…`NINE` at 4–13, plus
   `VELAPAW_KWS_DIGIT_OF()` / `LABEL_OF()` so callers never open-code the offset.
2. `voice/kws.cc` — label-name table extended, `static_assert`ed against the enum.
3. 🔴 **`AddConv2D()`, not `AddDepthwiseConv2D()`.** This section previously said the
   resolver needed no change at all. Half right: the slot count stays `<4>`, but the op
   is different — the shipped micro_speech model used a depthwise conv and `tiny_conv`
   emits a plain `CONV_2D` (verified against the op list in `kws_int8.tflite`). This is
   not a link error; it is `AllocateTensors` failing at boot with "Didn't find op for
   builtin opcode".
4. 🔴 **`KWS_CLASSIFIER_ARENA` 8 KB → 16 KB.** Also predicted wrong here: arenas do not
   scale with *class* count, true, but they do scale with the activations, and this
   architecture is different from the one that was measured at 6916 B. The conv
   activation is 25×20×8 = 4000 B and the flattened 4000 B feeding `final_fc` is live
   alongside the 1960 B input → peak ~10 KB. The board prints
   `kws: classifier ready, arena used N/16384 B`; shrink to the measured value.
5. **Leave `CONFIG_VELAPAW_KWS_SELFTEST` ON for the first boot** — reversing the
   instruction that stood here. The claim that "its vectors assert 4-label indices" was
   wrong: the two bit-exactness vectors test the *frontend* graph, which is unchanged,
   and the end-to-end clips assert `YES`/`NO`/`SILENCE` = 2/3/0, which the training
   label order deliberately preserved. It is the cheapest end-to-end proof that the new
   classifier works on known audio, before any microphone is involved. Turn it off
   afterwards to reclaim its ~98 KB (`Makefile:109-114`).

Model size goes 18,800 B → **59,024 B**. The `final_fc` head is 4000 × n_labels and
dominates — this architecture essentially *is* its classifier head.

### The two real risks (neither is model count)

1. **Continuous duty cycle on a single core.** `CONFIG_SMP` is off. Ungated KWS at a
   100 ms stride costs ~40 % of the core, permanently, against LVGL + camera + a
   1310 ms recognition. **Gate it behind VAD** — `apps/audioutils/speexdsp` is already
   in the tree. Cheap DSP decides "is anyone talking"; the expensive model only runs
   when the answer is yes. Quiet kitchen → model runs ~never.

2. **Audio underrun during the 1310 ms inference.** DMA keeps filling; if the drain
   thread isn't scheduled, samples vanish silently and the wake word is missed at
   exactly the moment a pet is at the bowl. Two mitigations, both must be designed in:
   - audio drain thread priority **above** the recognition worker
   - DMA buffers sized for ≥2 s (16 kHz × 16-bit mono = 32 KB/s → 64 KB PSRAM)

Do not enable `CONFIG_SMP` to solve this. Recall what `CONFIG_RTC` did to the console.

## PHASE 5 — Wire to the UI

Recognized word → the existing schedule path. Voice only has to produce a
**(slot, minute-of-day)** pair; storage already exists and is untouched:

```c
/* identity.h:20 */  int meal_min[VELAPAW_MAX_MEALS];   /* minute of day, -1 = off */
                     velapaw_identity_set_meals(..., const int *meal_min);
```

**Entry is a 🎤 button on Edit Schedule — there is no wake word.** Two reasons, and
both are decisions rather than shortcuts: "Hi VelaPaw" is not in Speech Commands, and
continuous listening costs ~40 % of the single core permanently (see the risks above).
A button is one tap the user was already making on that screen.

The dialog, one word per step:

```
🎤  "Meal? say 1, 2 or 3"        →  one|two|three   →  slot
    "Meal 1. Hour? say 0-9"      →  zero..nine      →  hour
    "08:00 — yes or no?"         →  yes|no          →  commit / retry
```

Each capture is ≈2 s of wall time; the whole dialog runs ≈10–12 s. A single spoken
digit plus the AM/PM sense carried by the confirm step reaches **00–09 and 12–21** —
which is every hour anyone actually feeds a pet. 10, 11, 22 and 23 fall back to the
`+`/`−` buttons that already exist, so nothing is unreachable.

**The pet is never spoken.** The camera identifies it — asking the owner to say a name
the model was never trained on would be strictly worse than the sensor already on the
board.

State machine: `IDLE → MEAL → HOUR → CONFIRM → DONE`, replacing `voice_apply()`, with
per-step thresholds — **0.45 MEAL / 0.73 HOUR / 0.59 CONFIRM on the raw softmax
probability of the best word legal at that step** (Phase 3 result; do not renormalise
over the subset) — a "say again" retry capped at three, a cancel button, and a
timeout. `VOICE_YES_SCORE 0.80` / `VOICE_NO_SCORE 0.60` at `ui_lvgl.c:451-452` are b54's
4-label numbers and are superseded for the dialog path. The screen
shows "🎤 Listening…" and echoes the recognized word — the 3.5" display is the audio
feedback channel, which is better than a beep and works even if the speaker path lags.
### The Chinese strings need no font work

A glyph outside the shipped 150-glyph subset renders **blank**, silently, with no
build error — so this was checked rather than assumed. The natural wording needs 13
missing glyphs (`、再几午否听或是次清聆说，`) plus the em-dash `—`, and
`NotoSansSC-Regular.otf` is not on the build machine.

It doesn't matter. The spoken words are English (`yes`, `one`, `eight`) because that
is what the model knows, so the Chinese only carries connective text and quoting the
English verbatim is correct rather than a compromise. Verified against the real glyph
set — every step covered, nothing regenerated:

```
S_VC_MEAL     第 %d 餐?  1 / 2 / 3
S_VC_HOUR     第 %d 餐。时? 0-9
S_VC_CONFIRM  %02d:00 - "yes" / "no"?     <- ASCII hyphen, the em-dash is missing too
S_VC_SAVED    已设置: 第 %d 餐 %02d:00
S_VC_RETRY    请重试
S_VC_CANCEL   已取消
S_VC_LISTEN   等待中...                    <- ASCII dots, U+2026 is missing
```

Downloading Noto Sans SC (OFL) and re-running `lv_font_conv` at all three sizes buys
nicer phrasing (请说…, 聆听中). That is an upgrade, not a dependency.

---

## Scope honesty

Free-form speech — *"velapaw schedule the first feeding time for pet king at 8"* as one
spoken sentence — **will not work on-device.** No ASR engine exists in the openVela
tree and there is no room for one. On-device gets you a guided dialog tree. The literal
sentence requires cloud NLU via `external/bailian_sdk` (`libqwen_sdk.a`,
`libc_mmi_cmd_voice_translate.a` are vendored in-tree). This is unchanged.

**Confidence, revised 2026-08-05.** This section used to read *"a usable keyword model
inside the remaining schedule is roughly a coin flip — the bet is the dataset and
training."* That bet no longer exists: the dataset is public, complete, and is the same
one that trained the model already recognising "yes" on this board at 0.98. What remains
is an overnight CPU run and a state machine, both of which are ordinary work with known
failure modes. The residual risk is narrow and named — **accent**, since Speech Commands
skews US English, and **digit confusability** (`three`/`free`, `nine`/`five`), which the
confirm step exists to absorb.

---

## OPEN: the intermittent setup panic (2026-08-03)

Two distinct, independent problems are now in play. Do not conflate them again.

**Problem A — the RX stall.** Capture delivers at most one buffer (usually zero), and
`VP: rx_worker fired` never recurs. **Still open.**

Patch **#16** (clear `I2S_TX_STOP_EN`, bit 13 of `I2S_TX_CONF_REG`, hardware default 1, in
`i2s_configure` at `esp32s3_i2s.c:1503`) was the clock-starvation theory: the bit stops
BCK/WS when the TX FIFO empties, and in full duplex RX is a slave borrowing those signals via
`I2S_SIG_LOOPBACK`. **#16 is now TESTED AND DISPROVEN** — build `nuttx-m18.bin` contains it,
reached the loop cleanly, and still produced zero RX completions. Keep or revert as
preferred; it changes nothing observable.

### The arithmetic that makes this hard to explain

The primed silent TX buffer is 8192 B = 4096 samples = **256 ms** of bit clock at
16 kHz/mono/16-bit. RX needs only 4092 B = 2046 samples = **128 ms** to reach
`I2S_RX_EOF_NUM`. Capture should complete *twice over* inside the single playback buffer we
know was transmitted. It completes zero times. So either the RX module is not being clocked
at all despite `I2S_SIG_LOOPBACK`, or the DMA in-channel is not advancing.

**The next test should be a measurement, not a patch:** from thread context (safe), on the
second `i2s_receive` call, dump `DMA_IN_INT_RAW_CH0`, `DMA_IN_SUC_EOF_DES_ADDR_CH0`,
`I2S_RX_CONF_REG`, `I2S_TX_CONF_REG`, and the `ctrl` word of each RX descriptor. That
distinguishes "no clock" from "DMA never armed" from "EOF fired but the ISR path is broken",
which three builds of inference have failed to separate.

### Ruled out for Problem A (do not re-investigate)

* RX IRQ never enabled — **false.** `esp32s3_i2s_initialize` calls `i2s_rx_channel_start`
  (`:3198`), which does `up_enable_irq(priv->rx_irq)` and sets
  `DMA_IN_SUC_EOF_CH0_INT_ENA` (`:2181-2184`) at boot.
* Codec register corruption (drafted patch **#8**, the shared `es8311_reset` wiping REG0A)
  cannot be the cause of *this* symptom. A wrong serial-port format yields **wrong data, not
  absent data** — the RX DMA counts clocked-in bytes regardless of content, so a format
  mismatch would still fire EOF. #8 may still be worth applying for audio *quality*, but it
  will not fix a stall.
* `i2s_tx_channel_stop` / `i2s_rx_channel_stop` are not called mid-run; `I2S_TX_START`
  stays set (`:2225`, `:2276` are the only clear sites, both on the stop path).

**Problem B — the intermittent panic.** `EXCCAUSE=001c` (LoadProhibited) in task `nxlooper`,
landing *after* the two benign `-22` configure lines and *before* the loopthread starts. High
base rate, not deterministic. Blocks testing Problem A, because most runs die before the loop.

### Localised, but not yet caught in the act

Probe patches **#17** (`VP: L1`…`VP: L6`, in `nxlooper_loopthread`) and **#18**
(`VP: M1`…`VP: M7`, in `nxlooper_loopback`) bracket every statement from the second
`AUDIOIOC_CONFIGURE` to the loopthread's first buffer. A run that *survived* printed all of
them in order, which rules the whole setup path healthy when it doesn't fault:

```
VP: M1 both configures done   VP: M2 bufinfo n=4   VP: M3 mq opened
VP: M4 record mq registered   VP: M5 play mq registered   VP: M6 pre pthread_create
VP: L1 loopback entry   VP: L2 rec bufinfo size=8192 n=4
VP: L3 rec[0..3] ret=8 want=8 apb=0x3c4bdac0/0x3c4bfb60/0x3c4c1c00/0x3c4c3ca0
VP: L4 enq rec[0..3] ret=0
VP: L5 play bufinfo size=8192 n=4   VP: L6 play[0..3] ret=8 (all non-NULL)
VP: primed TX with silence ret=0   VP: M7 loopthread created
```

**A panicking run must be captured with these probes in place** to name the statement. Until
then the location is only bounded, not known.

#### Inspection candidate, NOT confirmed and NOT consistent with the clean run

`nuttx/audio/audio.c`:

* `audio_allocbuffer:786-789` returns **0** *without writing* `*bufdesc->u.pbuffer` when
  `upper->periods >= upper->nbuffers`.
* `audio_enqueuebuffer:861-865` indexes `upper->apbs[priv->head % upper->periods]` on the
  `bufdesc->u.buffer == NULL` branch — with `periods == 0` that is a modulo by zero and a
  load through a possibly-NULL `upper->apbs`, which would give exactly `EXCCAUSE=001c`.

But the clean run shows `ret=8` (not 0) on all eight allocations and `nbuffers=4`, so the
early return did **not** fire there. This candidate explains a fault only if `upper->nbuffers`
is somehow 0 on the failing runs. Treat as unproven.

### Method rules earned the hard way

* Probes in `i2s_rx_schedule` / `i2s_rx_interrupt` are **ISR context** — `syslog()` there
  faults (`EXCCAUSE=0014`). Record into a static, print from thread context. Probes in
  `nxlooper.c` are thread context and safe.
* Absence of console output localises nothing (CDC-ACM discards the tail on panic).
* One clean run is not evidence. Repeat before attributing.

---

## 2026-08-03 — patch #20 tested and DISPROVEN; RX stall still open

### The fix that was tried

`esp32s3_i2s.c i2s_set_datawidth()` has the PCM / non-PCM branches **swapped for RX**
(compare the TX block ~30 lines above):

* TX: PCM -> `TX_TDM_WS_WIDTH = 1`, else -> `data_width - 1`
* RX: PCM -> `RX_TDM_WS_WIDTH = data_width - 1`, else -> **`1`**

We run standard I2S (non-PCM), so TX generated a 32-BCLK frame while RX was told the WS
pulse was 2 BCLK wide. This is a genuine upstream transposition bug and was fixed as
**patch #20a**, together with **#20b** (the RX branch never pulsed `I2S_RX_UPDATE`; TX does).

### Result: no change whatsoever

The RXDUMP came back **bit-for-bit identical** to the pre-#20 run:

```
rxconf=0008960c txconf=08089204 eofnum=00000ffc
raw=000000a0 link=001bb2c4 state=003fb2d0 fifo=0f810f16
eofdes=00000000 dscr=00000000 act=1 pend=1 done=0
d[0] ctrl=80000ff0   d[1] ctrl=80000010
```

Patch #20 **did execute** — `es8311_setbitspersample()` calls `I2S_RXDATAWIDTH` which reaches
`i2s_set_datawidth()`. So this is a tested-and-disproven fix, not an untested one. Keep the
patch (it is still correct), but it is not the cause.

### What the identical dump means

Changing the RX frame geometry changed nothing at all. If RX were merely *mis-framing* a
signal it could see, altering WS width would have changed *something* — a different byte
count, a descriptor error, garbage data. Zero change across a framing change means the RX
front end is receiving **nothing**, not misinterpreting something.

### Register decode, for the record

* `txconf=08089204` -> TX_START=1, master, TDM_EN=1, `SIG_LOOPBACK=1` (bit 27),
  `TX_STOP_EN=0` (patch #16 confirmed live on hardware).
* `rxconf=0008960c` -> RX_START=1, RX_SLAVE_MOD=1, RX_TDM_EN=1, RX_PDM_EN=0, PCM bypassed,
  RX_MONO=0. Configuration is correct.
* `link=001bb2c4` -> inlink armed at d[0], AUTO_RET set, `INLINK_PARK=0` (FSM running).
* `state=003fb2d0` -> `INLINK_DSCR_ADDR` = d[1]: loaded d[0], prefetched d[1], waiting.
* `raw=0xa0` -> only `INFIFO_FULL_WM` (5) and `INFIFO_UDF_L1` (7). Bits 0-4 (`IN_DONE`,
  `IN_SUC_EOF`, `IN_ERR_EOF`, `IN_DSCR_ERR`, `IN_DSCR_EMPTY`) all clear.

The GDMA is healthy and armed. Nothing is being handed to it.

### ⛔ METHOD FAILURE: the D: tree is NOT what runs in the VM

Proven twice on 2026-08-03:

1. The VM's `esp32s3_i2s.c` (git HEAD) lacks `#include <nuttx/mutex.h>`; the D: copy has it.
   A restore-from-git therefore would not link until the include was re-added.
2. `es8311.c` on D: still shows the `-ERANGE` configure bug: `ret = -ERANGE` is set, then
   `ret = es8311_setsamplerate(priv) == -ENOTTY ? OK : ret;` leaves `ret` at `-ERANGE` on
   success, and the following `if (ret < 0) break;` skips `es8311_setbitspersample()` and
   returns `-ERANGE` from `AUDIOIOC_CONFIGURE`. If that were the running code,
   `nxlooper_loopback` would abort at `nxlooper.c:1086` and never reach `VP: L1`. It reaches
   `L1`, so **the VM's es8311.c is patched and D:'s is stale.**

**Rule: do not reason about runtime behaviour from the D: sources.** Pull the actual file
from the VM first, or the analysis is worthless. Much of this hunt was inference from files
that do not match the binary — which is why repeated plausible fixes changed nothing.

### ⚠️ Source file was destroyed and rebuilt

A patch script used `io.open(p, "w", newline="\n")` where the escape had been eaten by a
quoted heredoc. `io.open` truncates the file when it opens the raw handle and validates
`newline` afterwards, so `esp32s3_i2s.c` went to **0 bytes**, taking patches #9/#10/#11/#16/#19
with it. Recovered via `git checkout` + a rebuild script.

**Rule: every patch script writes to `<file>.new` and `os.replace()`s it.** Never open the
target for writing directly.

### Status: RX capture does not work. Two paths remain.

1. **Hardware measurement.** Whether the ES8311 ADC drives anything on DIN (GPIO14) is now a
   scope/logic-analyser question, exactly as the SPI-LCD partial-window bug turned out to be.
   No amount of further register archaeology can answer it.
2. **Codec register readback.** Verify over I2C that the ADC is powered, unmuted and clocked.
   Needs `CONFIG_SYSTEM_I2CTOOL` (not currently in the defconfig) or a purpose-built probe.

Everything on the ESP32 side that can be verified from software has been verified. TX is
proven; RX is armed and starved.

---

## ✅ RESOLVED 2026-08-03 — Phase 1 step 3 complete

The section above is superseded. RX capture works, the loopback is audible, and the
captured stream is clean enough for `micro_speech`. No logic analyser was needed.

### Root cause: the RX TDM slot map was never programmed (patch #25)

Nothing in `esp32s3_i2s.c` ever wrote `I2S_RX_TDM_CTRL_REG`. `i2s_txchannels()`
programs `I2S_TX_TDM_TOT_CHAN_NUM` and the per-slot `CHANn_EN` bits for TX, but
`i2s_rxchannels()` is a **pure no-op** — it validates the channel count, stores
`priv->channels`, and programs no registers at all.

RX therefore sat at the hardware reset default `RX_TDM_TOT_CHAN_NUM = 0`, i.e. **one
slot per frame**, while `I2S_RX_CONF1_REG` described a **two-slot 32-bit frame**. The
receiver clocked and *completed* frames — `I2S_RX_DONE_INT_RAW` really did set — but
every slot was discarded before reaching the GDMA. Fix: mirror `i2s_txchannels()` on the
RX side inside `i2s_configure()`. `nbytes` went 0 -> 4092 immediately and stayed there.

### Why it took so long: every register read healthy

`RX_START=1`, clocks/dividers/framing/bit-width all correct, GDMA bound (`perisel=3`),
descriptors loaded, FSM running, `I2S_RX_DONE_INT_RAW` set. The only honest tells were
`DMA_IN_INT_RAW` bit 7 `INFIFO_UDF_L1` plus `EMPTY_L1` in `DMA_INFIFO_STATUS` (the GDMA
starving), and `IN_DONE` never firing.

**Lesson worth keeping: immunity to change is itself evidence.** Four consecutive
bit-identical RXDUMPs across four unrelated fixes meant the data was being discarded
downstream of everything being touched. That was under-weighted for several builds.

### Two throwaway diagnostics worth remembering

* **Pad-share loopback (#22)** — set `DINPIN = DOUTPIN = 16` and configure the pin
  `INPUT_FUNCTION_2 | OUTPUT`. Feeds TX's own data into RX with the codec out of circuit;
  proves the digital path with no scope and no soldering. Safe **only** on DOUT (the
  codec's high-Z input); never on DIN, which would contend with the codec's output.
* **Force RX master (#23)** — clear `I2S_RX_SLAVE_MOD` to test whether `I2S_SIG_LOOPBACK`
  really shares TX's BCLK/WS with a slave-mode RX. It does; RX was fine as a slave.
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

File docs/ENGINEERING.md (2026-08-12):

<b>English</b> | <a href="ENGINEERING_zh.md">中文</a>

# VelaPaw — Engineering Deep-Dive

Technical notes on how VelaPaw is built: the on-device AI pipeline, the depth of
openVela use, the hardest problems solved, and the performance engineering. This
is the companion to the [README](../README.md) for readers who want the details.

---

## 1. System at a glance

Everything runs on a single **ESP32-S3** (Xtensa LX7, 8 MB PSRAM, 16 MB flash)
under **openVela / NuttX**, with an **LVGL** touchscreen UI. There is no
companion phone, no cloud, and no network dependency — capture, inference,
scheduling, timekeeping and dispensing are all local.

**Flash layout (16 MB)**

| Offset | Contents | Size | Note |
|---|---|---|---|
| `0x000000` | Firmware (`nuttx.bin`) | ~750 KB | openVela + app + LVGL |
| `0x600000` | Identity model (`velapaw.tflite`) | 1.44 MB | flash-loaded to PSRAM at boot |
| `0x760000` | Body-condition model (`bcs.tflite`) | 626 KB | flash-loaded to PSRAM at boot |
| `0x800000` | Enrolled pets (magic `VPAW`) | 8 KB | names, schedules, face embeddings |
| `0x810000` | Pet photos (magic `VICN`) | 32 KB | card thumbnails |
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

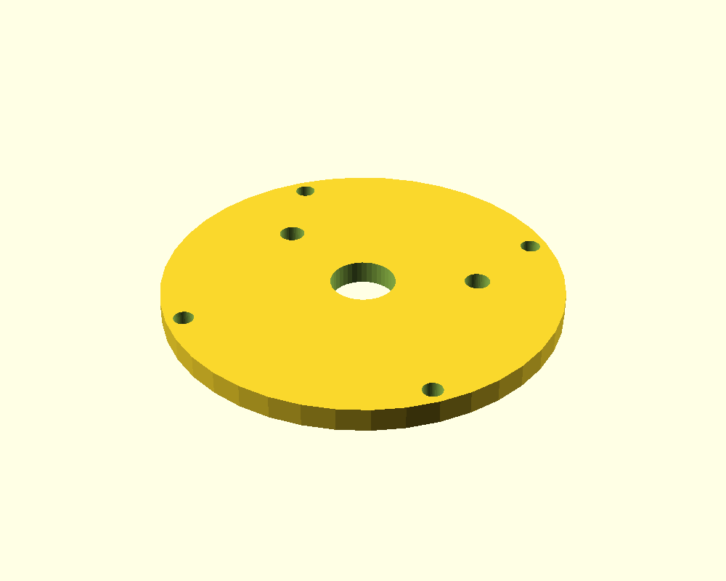
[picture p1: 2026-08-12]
hardware/preview/5_plate_stepper.png

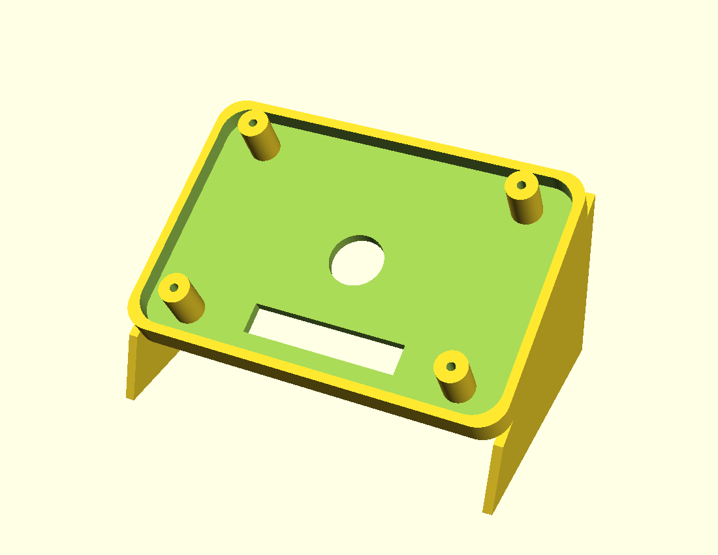
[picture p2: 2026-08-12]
hardware/preview/2_board_cradle_stand.png

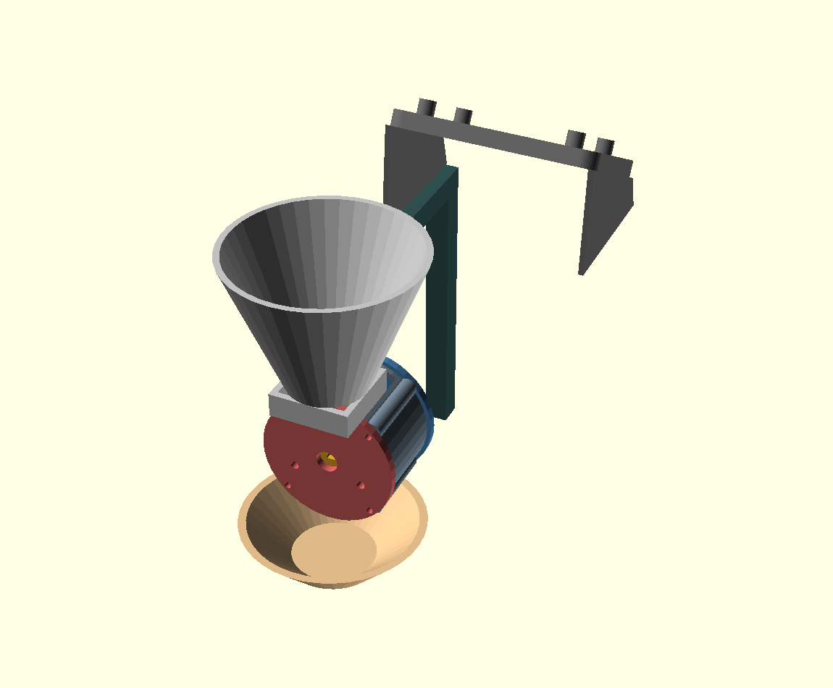
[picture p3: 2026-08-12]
hardware/preview/4_product.png

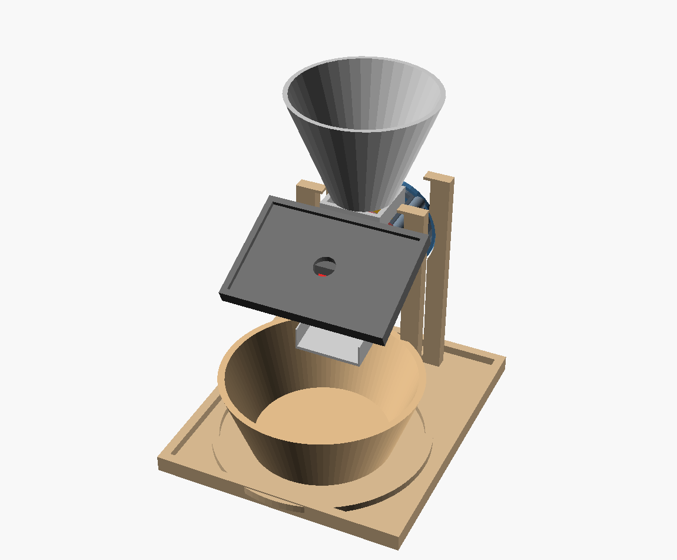
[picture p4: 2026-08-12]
hardware/preview/6_stand.png

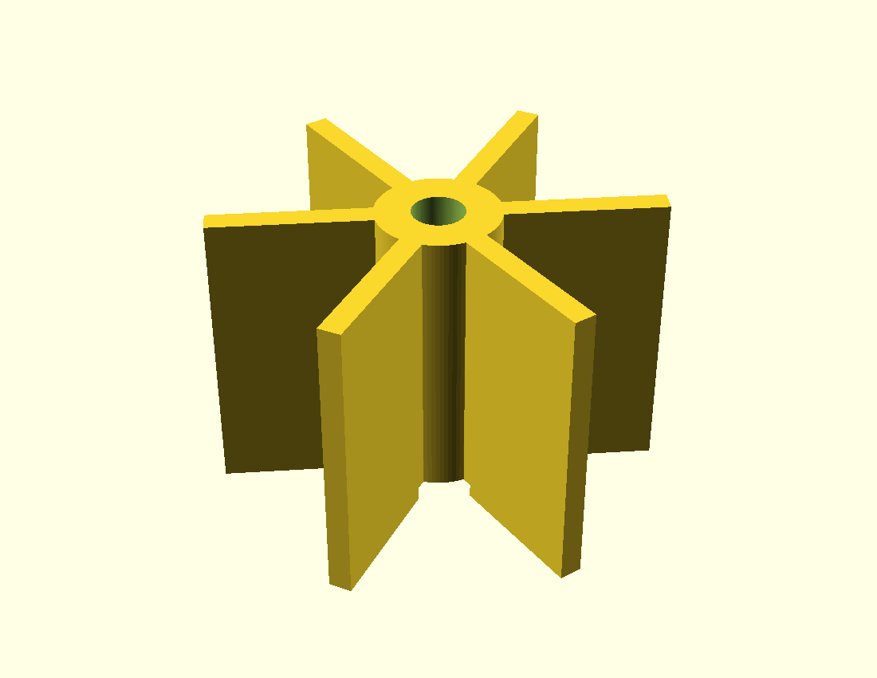
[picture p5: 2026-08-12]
hardware/preview/3_rotor.png

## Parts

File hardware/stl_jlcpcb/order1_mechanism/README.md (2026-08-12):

# Order 1 of 2 — the mechanism

Upload **all 7 files** in this folder as one JLCPCB job. Apply one ¥50 3D-printing
voucher here; the other goes on `../order2_structure`.

**Print this order in MJF PA12 nylon.** This folder holds every printed-to-printed
fit in the model (see below), and those fits want MJF's ±0.3 mm accuracy. The
229 cm³ here is the part of the job worth paying the nylon price for — the bulky,
fit-free structure goes to cheap FDM in `../order2_structure`. Est. **~¥120–180
after the voucher**. (The parts *will* assemble on FDM too if you must — every fit
is sized for ±0.5 — but MJF is the better mechanism.)

| File | Qty | Vol cm³ |
|---|---|---|
| `velapaw_rotor_x1.stl` | 1 | 21.0 |
| `velapaw_housing_x1.stl` | 1 | 17.5 |
| `velapaw_plate_stepper_x1.stl` | 1 | 15.6 |
| `velapaw_plate_idle_x1.stl` | 1 | 16.3 |
| `velapaw_hopper_x1.stl` | 1 | 49.2 |
| `velapaw_chute_x1.stl` | 1 | 22.6 |
| `velapaw_support_x2.stl` | **2** | 43.2 ea |
| **7 files, 8 pieces** | | **229 cm³** |

`support` is the only quantity-2 part — the drum sits in an A-frame at each end,
and one A-frame means the machine cannot be assembled. Set the quantity at the
cart; the filename is a reminder, not something JLC reads.

## Why these seven are together

**Every printed-to-printed fit in the whole model is inside this folder.** That
is the reason for the split line, not volume:

```
rotor  --running fit-->  housing        (0.8mm on radius, has to keep turning)
rotor  --stub socket-->  plate_idle
plates --bolted-------->  housing        (8x M3)
hopper --saddle-------->  housing OD  + post scallops
support--saddle-------->  plate OD       (SAD_R = PLATE_R + 1)
chute  --sits under---->  housing
```

Parts printed in one batch share their systematic error — same machine, same
flow calibration, same spool — so they miss in the *same direction*. Split
across two orders they can miss in opposite directions, which is exactly the
case every clearance in this model was sized against. Keeping the cluster
together doesn't make the fits legal; it makes them comfortable.

Nothing in `order2_structure` fits anything here except through a bolt hole, so
that folder can be printed on a different machine, in a different material, on a
different day, with no consequence.

See `../ORDER.md` for process settings, verification results and fasteners.

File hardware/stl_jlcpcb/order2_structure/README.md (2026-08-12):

# Order 2 of 2 — the structure

Upload **all 6 files** in this folder as one JLCPCB job. Apply the second ¥50
3D-printing voucher here; the first goes on `../order1_mechanism`.

**Print this order in FDM (PLA/PETG).** Nothing here has a printed-to-printed fit
— every interface is an M3/M4 clearance hole (see *Why these six are together*),
so FDM's looser ±0.5 mm costs nothing, and this is 403 cm³ (64 % of the whole
job), most of it a flat base plate. Paying MJF nylon prices for a plate that fits
nothing would be wasted money; the precision mechanism is what goes to MJF in
`../order1_mechanism`. Est. **~¥40–70 after the voucher**. (The one fit that was
re-solved for FDM, the board pocket, lives here and is already at 1.0 mm/side.)

| File | Qty | Vol cm³ |
|---|---|---|
| `velapaw_base_front_x1.stl` | 1 | 178.8 |
| `velapaw_base_back_x1.stl` | 1 | 94.1 |
| `velapaw_pedestal_x1.stl` | 1 | 46.3 |
| `velapaw_board_cradle_stand_x1.stl` | 1 | 45.5 |
| `velapaw_cam_pod_x1.stl` | 1 | 2.2 |
| `velapaw_cam_mast_x1.stl` | 1 | 35.9 |
| **6 files, 6 pieces** | | **402.8 cm³** |

The screen was **turned to face the owner**, so the camera can no longer look
over the top of it. It was **decoupled onto its own bracket**: the pedestal
reverted to its plain form (101.8 → 46.3 cm³, gantry removed) and the new
**`cam_mast`** is a two-leg **yoke** that bolts to `base_front` and stands
**straddling the chute** (feet at X ±34, the trough is only X ±23), carrying the
pod **centred just in front of the drum** where it aims steeply down — its
sightline passes *under* the owner-facing screen's bottom edge to reach the pet.
`base_front` gained 2 M3 holes for the yoke feet. See `../ORDER.md` → *The
relocated camera*.

## Why these six are together

They hold things up. **None of them has a printed-to-printed fit** — every
interface here is an M3 or M4 clearance hole, which does not care what machine
its mate came off. That is what makes this folder separable from
`order1_mechanism`, where all the real fits live. (The `cam_pod`→mast and
`cam_mast`→base joints are the same story: M3 through Ø3.4 clearances into pilots
or nuts — machine independent.)

`base_front` + `base_back` are two tiles of one plate, spliced with 2× M3 × 22.
They are two pieces only because the plate is longer than a 220mm bed.

## This folder is where the money is

**403 of the project's 632 cm³ — 64%.** And 273 cm³ of that (43% of the whole
job) is `base_front` + `base_back`: a flat 5mm plate with fourteen M3 holes.

**DECIDED (2026-07-25): it gets printed.** Substituting a cut sheet of MDF or
acrylic was considered and rejected, so upload all six files. This note exists
so nobody re-opens the question at the cart.

The floor thickness is **not** a free parameter if volume ever has to come out:
the M3 × 12 countersunk tower screws are dimensioned around exactly 5mm (csk
sinks 1.4, screw protrudes 7 into a 9mm flange). Thinning the floor means
re-solving the screw stack. Pocketing the floor *between* the tower feet and the
bowl ring is the change that saves volume without touching the fastener scheme.

See `../ORDER.md` for process settings, verification results and fasteners.

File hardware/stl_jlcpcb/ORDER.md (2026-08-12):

# VelaPaw feeder — JLCPCB 3D printing order

Generated from `../velapaw_feeder.scad`. Do **not** hand-edit these STLs; change
the `.scad` and re-export, or the two will drift apart.

## Order settings

| Field | Value |
|---|---|
| Process | **MJF or FDM** — this set assembles at either (SLS substitutes for MJF) |
| Material | **PA12 nylon** (MJF) / **PLA or PETG** (FDM) |
| Finish | as-printed / bead-blast natural grey (dyeing optional, purely cosmetic) |
| Tolerance | ±0.3 mm (MJF) or ±0.5 mm (FDM) — every fit is sized for the worse of the two |
| Units | **millimetres** |

**Either process works, and that is deliberate.** The general fit clearance is
`FIT = 0.6` per side, which already exceeds FDM's ±0.5 requirement, so the
mechanism assembles on a filament machine without touching the model. The one
fit that needed re-solving for FDM is the board pocket — see *The board pocket*
below. For a demo build FDM is roughly a fifth of the MJF price; MJF is the
better part.

**Recommended material split — MJF `order1_mechanism`, FDM `order2_structure`.**
The two orders are already divided along the only line that matters for this
choice: **`order1` holds every printed-to-printed fit, `order2` holds none**
(its parts touch the mechanism only through M3/M4 bolt holes). So print the
229 cm³ mechanism in **MJF PA12**, where dimensional accuracy earns its keep on
the rotor/housing/plate fits, and print the 403 cm³ of structure — a flat base
plate and brackets that fit nothing precisely — in cheap **FDM**. That buys
accuracy only where it's needed and pays filament prices for the 64 % of the
volume that is bulk. This is optional (both orders print either way), but it is
the cost-optimal way to order and the two folders were split to make it clean.
See *Material volume* for the per-order cost.

## Parts — 13 files, 14 pieces, split across TWO orders

JLC allow **one coupon per order**, and there are two ¥50 3D-printing vouchers
(`openvela`, no minimum, expiring 2026-10-31). Two orders redeem both. The files
are already sorted into the folders to upload — and each folder is also zipped
(`order1_mechanism.zip`, `order2_structure.zip`, STLs only) so you can **drag one
zip per JLC job** instead of selecting files. Re-zip if you re-export any STL.

### `order1_mechanism/` — 7 files, 8 pieces, 229 cm³

| File | Qty | Size (mm) |
|---|---|---|
| `velapaw_rotor_x1.stl` | 1 | 50.3 × 56.4 × 38 |
| `velapaw_housing_x1.stl` | 1 | 64 × 64 × 39.2 |
| `velapaw_plate_stepper_x1.stl` | 1 | 72 × 72 × 4 |
| `velapaw_plate_idle_x1.stl` | 1 | 72 × 72 × 11 |
| `velapaw_hopper_x1.stl` | 1 | 96 × 96 × 80.7 |
| `velapaw_chute_x1.stl` | 1 | 46 × 108 × 92.5 |
| `velapaw_support_x2.stl` | **2** | 90 × 167 × 16 |

### `order2_structure/` — 6 files, 6 pieces, 403 cm³

| File | Qty | Size (mm) |
|---|---|---|
| `velapaw_base_front_x1.stl` | 1 | 164 × 176 × 15 |
| `velapaw_base_back_x1.stl` | 1 | 164 × 92 × 15 |
| `velapaw_pedestal_x1.stl` | 1 | 110 × 88 × 102 |
| `velapaw_board_cradle_stand_x1.stl` | 1 | 100.7 × 81.4 × 81.0 |
| `velapaw_cam_pod_x1.stl` | 1 | 35 × 20 × 8 |
| `velapaw_cam_mast_x1.stl` | 1 | 78 × 23 × 123 |

The screen was **turned to face the owner**, which killed the old over-the-top
camera path (the display now sits between any behind-the-bowl lens and the pet).
So the camera was **decoupled from the pedestal**: the pedestal reverts to its
plain form (46 cm³, was 102 with the gantry), and the OV5640 now rides its own
**`cam_mast`** — a two-leg **yoke** that bolts to `base_front` and stands
**straddling the chute**, carrying the pod **centred just in front of the drum**
where it aims steeply down; its sightline passes *under* the owner-facing screen's
bottom edge to reach the pet. `cam_pod` is the small open-back enclosure that holds
the bare module and bolts to the yoke's central pad with 2× M3. All ride
`order2_structure` because every joint here is an M3 clearance — machine
independent. See *The relocated camera* below. **Pod
pocket is built to the wide-angle MAX OV5640 envelope; if the real module is
calipered, tightening `POD_PCB` re-exports both the pod and the mast (the pad
hole spacing tracks the pod outline).**

`support` is the **only** part with quantity 2 — the drum sits in an A-frame at
each end. The quantity is in the filename because it is the single easiest thing
to get wrong at the cart, and a missing A-frame means the machine cannot be
assembled at all.

### Where the split line was drawn

**Not by volume — by fits.** Every printed-to-printed fit in the model is inside
`order1_mechanism`: the rotor's running fit in the housing, its stub socket in
the idle plate, the hopper's saddle over the housing OD and its post scallops,
the A-frames' saddles over the plate ODs, the chute under the drum. Parts printed
in one batch share their systematic error — same machine, same flow calibration,
same spool — so they miss in the *same* direction. Split across two orders they
can miss in opposite directions, which is the worst corner every clearance was
sized against. Keeping the cluster together doesn't make the fits legal; it makes
them comfortable.

Nothing in `order2_structure` touches the mechanism except through an M3 or M4
clearance hole, which does not care what machine its mate came off. That folder
can be printed on a different machine, in a different material, on a different
day, with no consequence.

Both orders clear ¥50 of value at the bottom of the FDM range, so neither
voucher is wasted. **Do check the second shipping fee at checkout** — it is the
one cost that splitting adds, and it comes straight off the ¥50 gained.

To order everything as a single job instead, upload both folders together — but
that redeems only one ¥50.

## Deliberately NOT in this folder

* **`board_cradle`** — the plain cradle. It is an *alternative* to
  `board_cradle_stand`, not an addition: the stand version contains the cradle.
  Ordering both wastes money and yields a part with nowhere to go. The stand
  version is the one the finished appliance uses.
* **`plate_servo`** — legacy MG90S mount, superseded by the stepper. Unused.
* **`stand`, `product`, `all`** — preview assemblies, not parts. `stand` is
  268 mm and exists only to show how the five stand pieces bolt together.

## The board pocket

`board_cradle_stand` holds the ESP32-S3-Touch-LCD-3.5-C in a pocket, and that
pocket is the **only fit in the model that had to be re-solved for FDM**. It is
also the only one where a bad outcome is not recoverable: everything else can be
reamed, filed or shimmed, but if this comes out tight the display does not seat
and the demo has no screen.

The pocket is 95.11 × 63.67 mm — the largest feature in the model, so it sees
the full tolerance swing. At the old 0.6 mm/side (sized for MJF's ±0.3) an FDM
pocket printed to the tight end of ±0.5 would have left **0.1 mm**. It is now
**1.0 mm/side**, which leaves 0.5 mm at the same bad corner.

Opening a pocket costs grip, because the retention lips start at the pocket wall
and retreat with it. `BM_LIP_W` went 2.0 → 2.8 to pay that back, restoring the
designed 1.8 mm of grip nominal / 0.8 mm with the board shoved fully to one side.
Two supporting changes came with it: the pocket wall went 2.4 → 2.8 nominal so
the *printed* wall stays at 1.8 mm (1.3 mm worst case) instead of dropping under
JLCPCB's 1.2 mm FDM minimum, and the lip's retaining face went 1.2 → 1.6 mm to
get off that minimum, since it is the face that takes the whole pull-out load.

Verified by solid-geometry probe, not by arithmetic alone:

| Probe | Expected | Result |
|---|---|---|
| case seats in pocket, nominal | empty intersection | clear |
| case seats with pocket 0.3 mm undersize (MJF worst case) | empty | clear |
| case seats with pocket 0.5 mm undersize (**FDM worst case**) | empty | clear |
| far lip still over the board, board shoved 1.0 mm away | **non**-empty | material present |
| enlarged cradle vs. every neighbour in the assembly | 13 separate bodies | 13 |

Net cost: the part grew 0.8 mm in each outer dimension and 3 cm³ in volume.
Nothing is competing for that space.

## The relocated camera

The OV5640 was unplugged from the board's 24-pin DVP connector and moved onto a
30 cm FFC so it can look at the bowl instead of riding the screen. **The screen
now faces the owner** (the board is un-rotated on its wedge), which means a
camera behind or above the bowl would have to shoot *through* the display — so
the camera is decoupled onto its own bracket. Two printed parts carry it:

* **`cam_pod`** — a small open-back enclosure for the bare module. Built to the
  **wide-angle MAX OV5640 envelope** (14 mm square PCB, 15 mm barrel aperture)
  because the exact module was not calipered; a smaller real part just sits
  looser and is taken up by a bead of silicone from the open back. Nothing rigid
  touches the barrel — it may be an auto-focus VCM element that jams if pressed.
  The lens tip stands proud of the front plate, so even a 120° cone never
  vignettes. Two Ø3.4 ears bolt it to the yoke pad.
* **`cam_mast`** — a two-leg **yoke** (78 × 23 × 123 mm, ~36 cm³) that bolts to
  `base_front` with **2× M3** and stands **centred, straddling the chute**: the
  feet are at X ±34 (the trough is only X ±23), so the legs rise vertically
  *outboard* of the chute, then knee inward above the rails and each arm lands on
  its own ear of a tilted pad. That pad, built in the pod's own frame, carries the
  pod's two ears **just in front of the drum**, and is cut with a central
  **window** so the pod's open back stays open — that is how the OV5640 seats
  (drop the PCB in, silicone bead from behind) and how the FFC tail routes up past
  the pad. It is a **separate bolt-on part**, so the pedestal reverted to its
  plain 46 cm³ form.

The pod sits central (X = 0), so the aim is a **pure steep down-tilt**: the pod
swings 180° about Z and tilts 68.3° about X to lay its lens onto the pet-face
target. The key trick is occlusion — a level camera here would shoot into the
back of the owner-facing screen, but from this low eye (z ≈ −13) the steep ray
drops below the screen's z = −20 bottom edge before reaching it and lands on the
pet over the bowl. Validated in the assembly by CGAL: pod, yoke and the aim
sightline each clear the board, hopper, drum, bowl, chute and pedestal (empty
intersections), and `cam_mast` is one closed solid (`Simple: yes`, one volume).

**Caution — orientation before power.** A reversed FFC is fatal on first power:
board pin N mates camera pin 25−N, which puts a 1.5 V rail onto the camera's
ground and 2.8 V onto data lines. Before powering, buzz chassis ground to the
coupler's far contacts and confirm ground lands on the low-numbered (pin-2) end;
flip the cable if it shows at the pin-23/24 end.

**Caliper note.** If the real module is measured, tightening `POD_PCB` in the
`.scad` re-exports **both** `cam_pod` and `cam_mast` — the yoke pad's hole
spacing tracks the pod outline (`EAR_X = POD_OUT/2 + POD_EAR_L/2`). Re-run the
two exports and the numbers above will shift slightly.

## Pre-upload verification (measured on THESE files, not on the source)

Run `verify_stl.py` and `bedcontact.py` against **each order folder** to
reproduce. Both folders were re-verified after the split — the checks below are
the union of the two runs, and nothing changed in the move.

**Watertight — all 13 pass all four conditions.** "Watertight" is four separate
things, and a mesh can pass the naive check and still be rejected. The order2
files touched by the front-camera pivot (`base_front` gained 2 yoke-foot holes,
`pedestal` reverted, `cam_pod` unchanged, `cam_mast` the drum-front yoke) were re-verified by
CGAL (`Simple: yes`, one closed volume each) and z=0 seating:

| Condition | Result |
|---|---|
| every edge shared by exactly 2 triangles (no holes/open edges) | 0 open edges |
| consistent winding — each directed edge used once | 0 bad |
| signed volume > 0 (normals point **out**, not in) | all positive |
| exactly 1 connected component per file | all 1 |
| zero-area/degenerate triangles | 0 |

**Orientation — all 13 sit on z = 0.000 on a real FACE**, not an edge or a
vertex. First-layer contact area, which is the check that actually matters:

| Part | bed contact | height |
|---|---|---|
| base_front | 28738 mm² (100% of footprint) | 15 |
| base_back | 14835 mm² (98%) | 15 |
| plate_idle | 4028 mm² (78%) | 11 |
| plate_stepper | 3904 mm² (75%) | 4 |
| support | 4652 mm² (31%) | 16 |
| rotor | 549 mm² (19%) | 38 |
| cam_pod | 208 mm² (front plate, 54%) | 8 |
| cam_mast | 240 mm² (2 feet, 100%) | 123 |
| housing | 629 mm² (15%) | 39.2 |
| hopper | 886 mm² (10%) | 80.7 |
| chute | 430 mm² (9%) | 92.5 |
| pedestal | 709 mm² | 102 |
| board_cradle_stand | 388 mm² (5%) | 81.0 |

The **pedestal is back to 102 mm tall** — the camera gantry is gone, so the post
reverts to its plain form and lands on the same 709 mm² of foot pads at z=0.
`cam_mast` is a 123 mm two-leg yoke that stands on its two 10 × 12 feet (both flat
on z=0); on FDM the inward-leaning struts and the tilted pad at the top want
support, on MJF it is a non-issue.

The low-ratio parts are tall and open by design; every one still lands on a flat
face. **On MJF none of this is binding** — it is a powder bed, JLC nest the parts
themselves, and there is no bed adhesion to lose. The poses are submitted correct
anyway because they make JLC's preview legible and they are what proves the set
could be made on a filament machine if it ever has to be.

## Material volume — read this before ordering

**632 cm³ total, ~0.63 kg of PA12** (includes support ×2). MJF is quoted mostly
by volume, so this is the number that sets the price. (Was 651 with the pedestal
gantry; the front-camera pivot dropped the gantry −55.5 cm³ off the pedestal and
added the `cam_mast` yoke +35.9 cm³, a net −20.)

Nearly half of it is still the base plate:

| | cm³ | share |
|---|---|---|
| base_front | 178.8 | 28% |
| base_back | 94.1 | 15% |
| **base plate subtotal** | **272.9** | **43%** |
| everything else (11 parts, 12 pieces) | 359.1 | 57% |

By order: `order1_mechanism` 229 cm³ (36%), `order2_structure` 403 cm³ (64%).
The structure order is the bulkier one, and it carries the camera as well:
base plate 273, pedestal 46, board cradle 45, pod 2, yoke 36.

**Per-order cost, using the recommended MJF/FDM split** (estimates in ¥; JLC
rates and region shift these, so treat as order-of-magnitude, and the 5-min
voucher check at the cart is what confirms them):

| Order | Material | Volume | Est. before voucher | After −¥50 |
|---|---|---|---|---|
| `order1_mechanism` | **MJF PA12** | 229 cm³ | ~¥170–230 | ~¥120–180 |
| `order2_structure` | **FDM PLA/PETG** | 403 cm³ | ~¥90–120 | ~¥40–70 |
| **both** | | 632 cm³ | | **≈ ¥160–250** |

For comparison: **all-FDM** ≈ ¥60–110 (weak fits on the mechanism), **all-MJF**
≈ ¥300–500 (overkill on the base plate). The split lands between the two and
puts the money where the tolerance actually matters. Watch the **second shipping
fee** — splitting adds one, and it comes off the ¥50 the second voucher gains.

That base plate is a 5 mm solid floor over 164 × 176 and 164 × 92 mm.

**DECIDED (2026-07-25): the base plate is being printed.** Substituting a cut
sheet of MDF or acrylic was considered and rejected, so the full base plate
stands (273 cm³ of the 632) and the two-order split holds as described above. Do
not re-open this at the cart.

If volume ever does have to come out of it, the thing to know is that the floor
thickness is **not** a free parameter: the M3 × 12 countersunk tower screws are
dimensioned around exactly 5 mm (csk sinks 1.4, screw protrudes 7 into a 9 mm
flange). Thinning the floor means re-solving the screw stack. Pocketing or
ribbing the floor *between* the tower feet and the bowl ring is the change that
saves volume without touching the fastener scheme.

## Sanity checks to run in JLC's uploader

1. **Scale.** `velapaw_base_front_x1` must read ~**164 × 176 × 15 mm**. STL
   carries no units; if the viewer shows inches or centimetres the whole order
   is wrong by a constant factor and every part will be useless.
2. **Watertight / manifold.** All thirteen pass locally — CGAL reports
   `Simple: yes`, one closed volume, zero bad edges. If JLC's checker disagrees,
   suspect the upload, not the geometry.
3. **No trapped powder.** No part has an internal void, so there is nothing for
   un-sintered powder to be sealed inside. The deepest blind holes are the four
   ⌀1.7 × 12 pilots down the cradle posts, which are vestigial on the -C board
   (see `BM_SCREW_D` in the .scad) — they may be ignored or filled.

## Fasteners — buy separately, NOT printed

| Item | Qty | Where |
|---|---|---|
| M3 × 12 countersunk | 12 | towers → base plate (2 per foot, 6 feet) |
| M3 × 22 socket cap | 2 | base_front → base_back splice |
| M3 (plates → housing) | 8 | end plates onto the drum |
| M4 | 2 | 28BYJ-48 stepper flange |
| M3 × 8 self-tapping | 2 | camera pod → yoke pad (through Ø3.4 ears into Ø2.6 pilots) |
| M3 × 12 | 2 | camera yoke feet → base_front (Ø3.4 clearance, nut under the plate) |

## After delivery

The 28BYJ-48 D-shaft socket in the rotor is the one fit deliberately held
tighter than the MJF clearance rule, because it is the only joint transmitting
torque and slop there means mis-dosing. At the tight end of the tolerance it
will need a 5 mm drill run through by hand and a light file on the two flats.
Budget 30 seconds for it; it is intentional, not a defect.

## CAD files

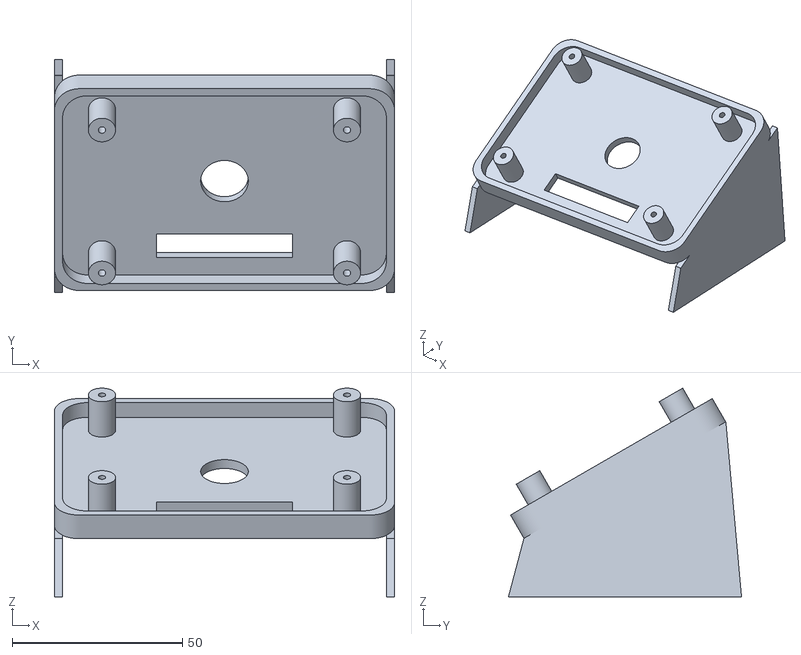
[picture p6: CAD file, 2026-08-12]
hardware/stl/board_cradle_stand.stl
99.9 x 68.5 x 61.4

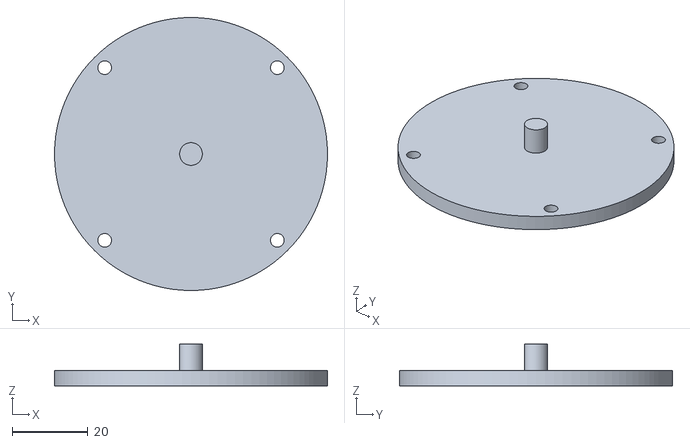
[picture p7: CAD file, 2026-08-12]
hardware/stl_jlcpcb/fixed_reupload/velapaw_plate_idle_v2_x1.stl
72.0 x 72.0 x 11.0

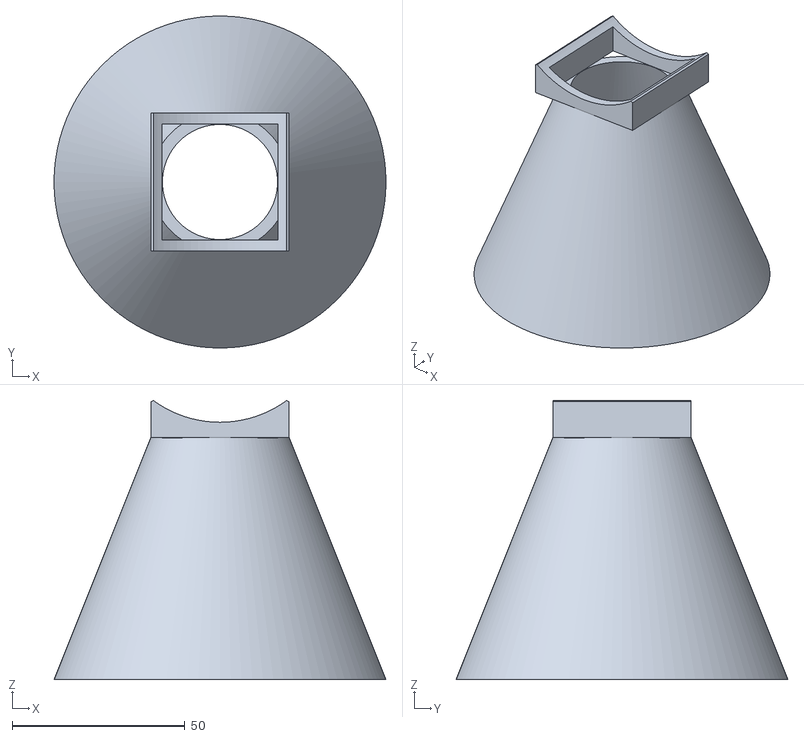
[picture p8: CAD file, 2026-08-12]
hardware/stl_jlcpcb/order1_mechanism/velapaw_hopper_x1.stl
96.0 x 96.0 x 80.7

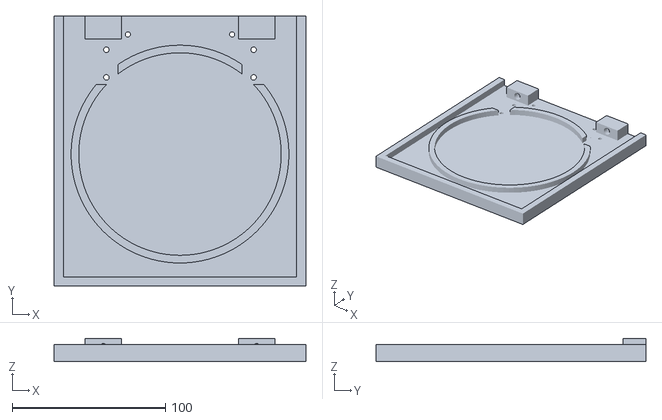
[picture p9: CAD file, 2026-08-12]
hardware/stl_jlcpcb/order2_structure/velapaw_base_front_x1.stl
164.0 x 176.0 x 15.0

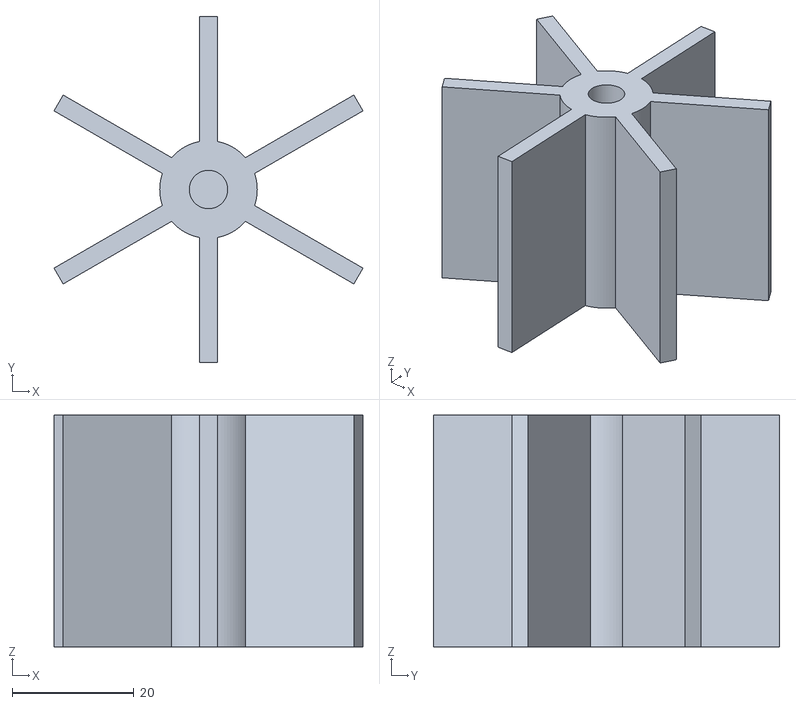
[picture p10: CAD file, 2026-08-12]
hardware/stl/rotor.stl
50.7 x 56.8 x 38.0

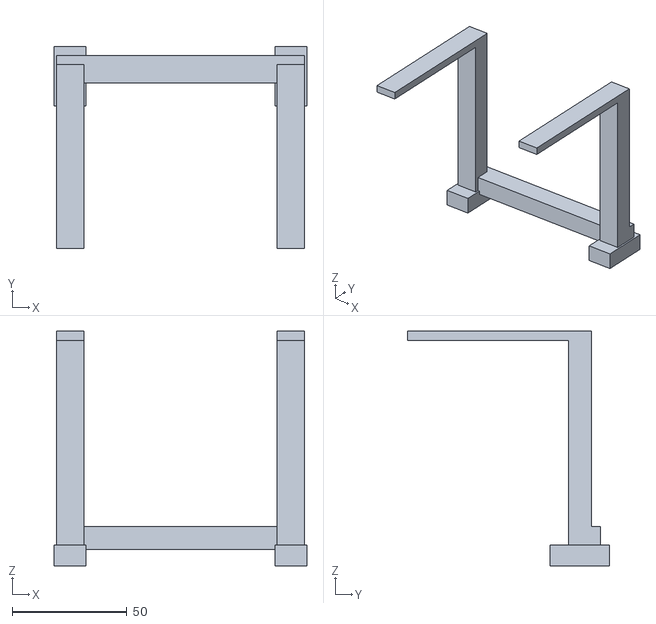
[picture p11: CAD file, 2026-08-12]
hardware/stl_jlcpcb/fixed_reupload/velapaw_pedestal_v2_x1.stl
110.0 x 88.0 x 102.0

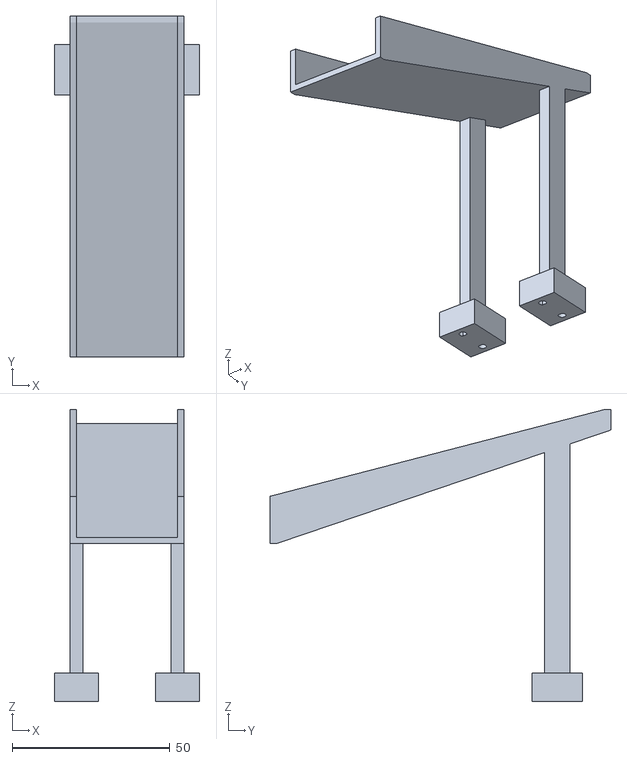
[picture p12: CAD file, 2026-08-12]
hardware/stl_jlcpcb/order1_mechanism/velapaw_chute_x1.stl
46.0 x 108.0 x 92.5

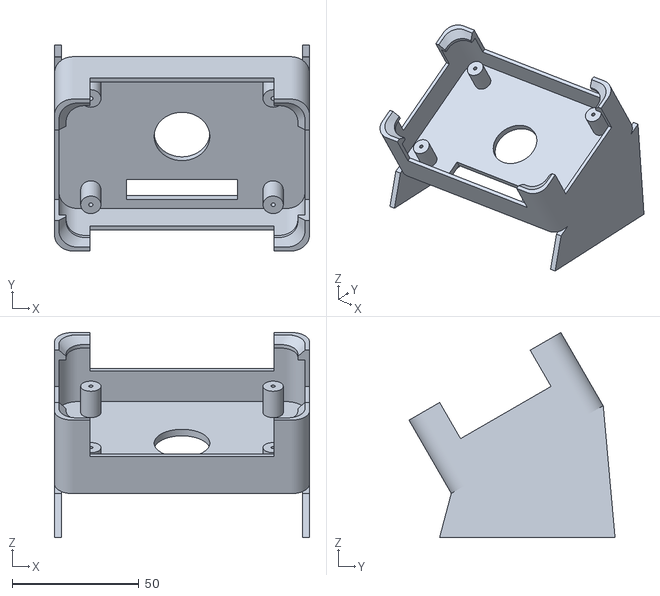
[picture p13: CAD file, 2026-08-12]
hardware/stl_jlcpcb/order2_structure/velapaw_board_cradle_stand_x1.stl
100.7 x 81.4 x 81.0

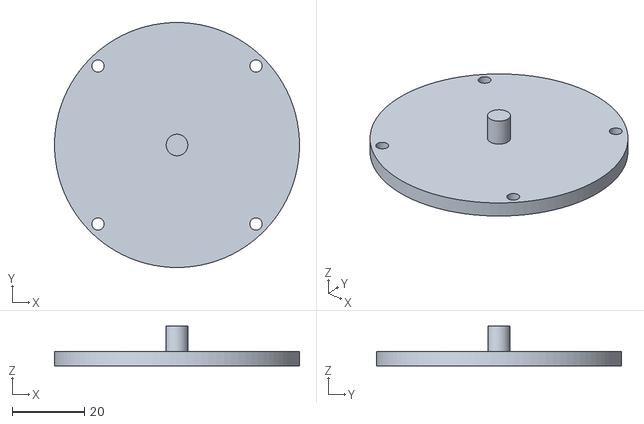
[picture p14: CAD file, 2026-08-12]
hardware/stl/plate_idle.stl
68.0 x 68.0 x 11.0

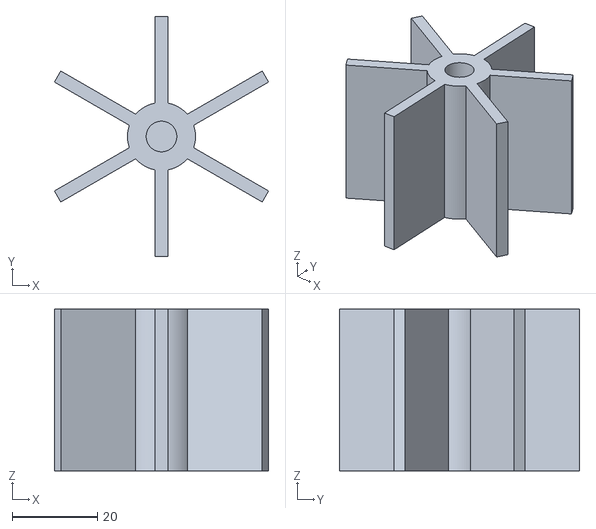
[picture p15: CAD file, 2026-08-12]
hardware/stl_jlcpcb/order1_mechanism/velapaw_rotor_x1.stl
50.3 x 56.4 x 38.0

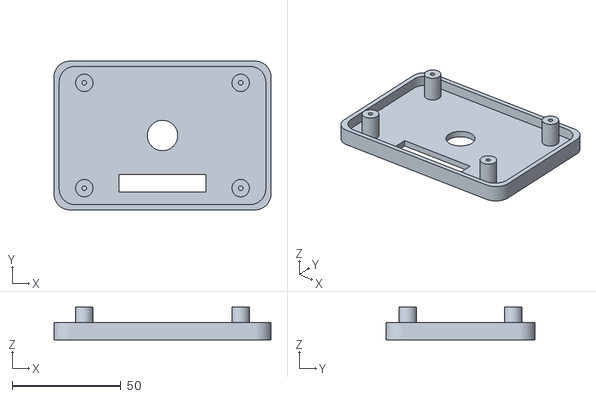
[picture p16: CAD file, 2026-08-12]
hardware/stl/board_cradle.stl
99.9 x 68.5 x 15.0

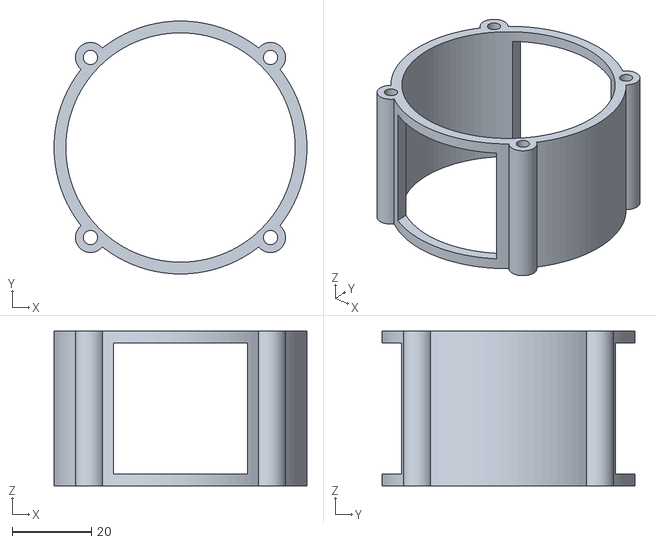
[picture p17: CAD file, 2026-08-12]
hardware/stl_jlcpcb/fixed_reupload/velapaw_housing_v2_x1.stl
64.0 x 64.0 x 39.2

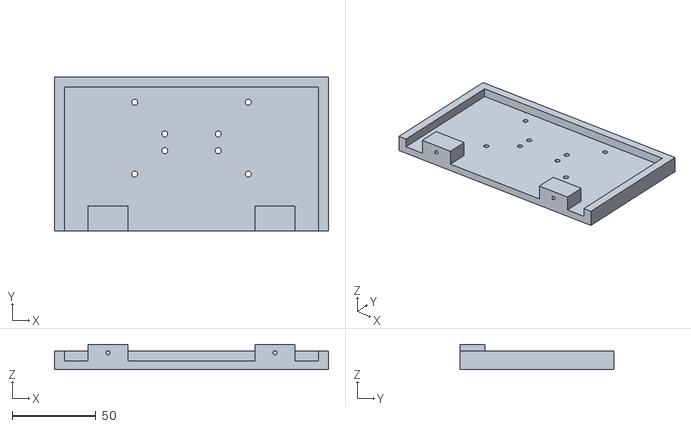
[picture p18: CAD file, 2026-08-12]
hardware/stl_jlcpcb/order2_structure/velapaw_base_back_x1.stl
164.0 x 92.0 x 15.0

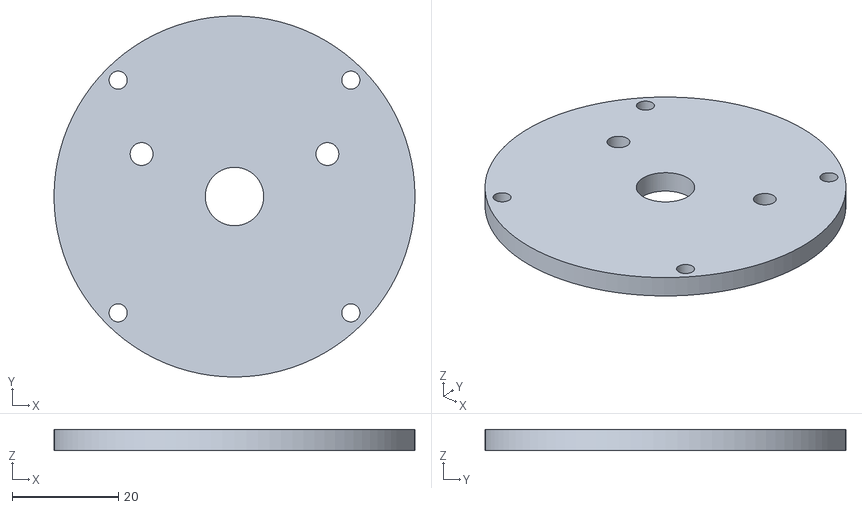
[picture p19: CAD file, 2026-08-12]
hardware/stl/plate_stepper.stl
68.0 x 68.0 x 4.00

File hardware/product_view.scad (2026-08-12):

// Whole-product concept view. Open this in OpenSCAD and press F5 (Preview).
// It pulls the real modules from velapaw_feeder.scad and shows product().
use <velapaw_feeder.scad>
product();

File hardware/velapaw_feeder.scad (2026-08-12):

// ============================================================================
// VelaPaw - paddle-rotor feeder  (contest 2026, team 043)
//
//   hopper  ->  rotor housing  ->  chute  ->  bowl
//
// The rotor is a vaned wheel turning inside a round housing under the hopper.
// Each vane pocket holds a FIXED VOLUME, so the dose depends on how many
// pockets the servo indexes -- not on how long a gate is held open, and not on
// how full the hopper is. That is the whole point: a flap dispenses more when
// the hopper is heavy, which would quietly break the per-pet portion control
// the product is built on.
//
// Driven by a 28BYJ-48 STEPPER (via a ULN2003 board), NOT a servo. A stepper
// rotates CONTINUOUSLY in one direction, so pockets ratchet inlet(top) ->
// outlet(bottom) without ever reversing. Each pocket = 60 degrees = one sixth
// of a turn = STEP_PER_POCKET half-steps in the firmware. So per-pocket dosing
// is exact:  grams = pockets x GRAMS_PER_POCKET  (calibrate by weighing one
// pocket's drop). Keep POCKETS here == ROTOR_POCKETS in the board file.
// (History: a 180-deg servo was tried first, but with the inlet/outlet 180 deg
//  apart its oscillation has zero net rotation and can't carry a pocket across
//  -- it dead-heads. The stepper's continuous spin is what makes the rotary
//  valve actually work and the portion-control claim literally true.)
//
// PRINTING -- JLCPCB MJF / SLS, PA12 nylon
// 12 printable parts in the dropdown, but you ORDER 11 FILES / 12 PIECES:
// board_cradle and board_cradle_stand are ALTERNATIVES (the stand contains the
// cradle -- order one, never both), and the A-frame support is the one part with
// quantity TWO. The ready-to-upload set with the quantities in the filenames is
// in stl_jlcpcb/, with ORDER.md beside it; regenerate it from this file rather
// than editing those STLs.
// Leave PRINT_POSE on and each part exports already rotated and sitting on z=0;
// the PRINT POSES block at the bottom of the file has the measured bed sizes and
// the reasoning behind each orientation. Nothing here exceeds 220 x 220 x 250.
//
// MJF was chosen over FDM for three reasons, in order of how much they matter:
//   1. IT IS A POWDER BED, SO THERE ARE NO SUPPORTS. Three parts (chute,
//      pedestal, board_cradle_stand) carry deliberate overhangs that no rotation
//      puts on a bed -- their open centres are the whole point of the design.
//      On FDM each needs support material printed into and then broken out of
//      the exact surfaces that have to stay clean. On MJF the problem does not
//      exist. The "supports?" column in PRINT POSES is FDM advice, kept because
//      it is still true if anyone reprints this on a filament machine.
//   2. TOLERANCE. +/-0.3mm instead of FDM's +/-0.5. The board pocket is 95.11mm
//      across and has to receive a purchased case; at +/-0.5 the clearance
//      needed to guarantee it seats is more than the locating wall can give.
//   3. PA12 NYLON FLEXES INSTEAD OF SNAPPING, which is what the four corner
//      snap clamps on the board mount actually want. They are 2.4mm columns
//      sprung sideways every time the board comes out; in PLA that is a fatigue
//      crack waiting to happen.
// The cost is that every fit between two printed parts needs 0.6mm per side --
// see FIT near the top of the parameters. That is why the running clearances in
// this file are looser than they would be for a filament print.
//
// Two things to hand the vendor:
//   * Orientation is ADVISORY. JLC nest parts in the powder bed themselves, so
//     the poses below are for your own inspection, not a build instruction.
//   * No part has an internal void, so nothing traps un-sintered powder --
//     every one comes back from CGAL as a single closed volume. The only deep
//     blind holes are the four 1.7 x 12 pilots down the cradle posts, and on the
//     -C those are vestigial anyway (see BM_SCREW_D).
//
//   FEEDER MECHANISM
//   part="rotor"         - flat, hub up. No supports.
//   part="housing"       - bore vertical. No supports (34mm bridges over the
//                          inlet/outlet, which any printer handles).
//   part="plate_stepper" - flat. No supports. (28BYJ-48 mount; plate_servo is
//                          the old MG90S mount, kept only for reference.)
//   part="plate_idle"    - flat, boss up. No supports.
//   part="hopper"        - MOUTH DOWN. No supports. It is FLIPPED from the way
//                          it is modelled: the drum saddle eats the whole neck
//                          face, so neck-down there is literally nothing to
//                          start on. See PRINT POSES.
//
//   BOARD MOUNT (print one or the other, not both -- the stand contains the
//   cradle). Holds the ESP32-S3 screen-UP with the camera looking down.
//   part="board_cradle"  - flat, clamps up. No supports (45deg lead-in ramps).
//   part="board_cradle_stand" - the cradle riding a 30-degree wedge, flat feet
//                          down. SUPPORTS under the tray. THIS is the mount the
//                          finished appliance uses (it drops onto the stand's
//                          pedestal); also works as a stand-alone desk stand.
//
//   STAND -- five printed pieces that bolt together. part="stand" is a PREVIEW
//   of them assembled and is 164 x 268 x 172: do not try to print it.
//   part="base_front"    - floor down. No supports. Bowl end of the base plate.
//   part="base_back"     - floor down. No supports. Column end. Bolts to
//                          base_front at BASE_SEAM_Y with 2x M3x22 socket cap.
//   part="support"       - PRINT TWO. Lies flat on its face, 90 x 167 x 16.
//                          No supports.
//   part="chute"         - pads down. SUPPORTS under the trough.
//   part="pedestal"      - posts up. SUPPORTS under the rails and tie bar.
//   The three towers then bolt DOWN through the base plate, 2x M3x12 countersunk
//   per foot -- 6 feet, 12 screws. Join the two base tiles FIRST: the splice
//   bosses sit inside the tray and a fitted tower is in the way.
//
//   part="all"           - preview of the assembly (do NOT print this).
//
// AFTER PRINTING - calibrate once:
//   Fill the hopper, dispense a single pocket, weigh what lands in the bowl.
//   Put that number in GRAMS_PER_POCKET in the board file. Done -- portions are
//   then correct for the rest of the machine's life, at any hopper level.
// ============================================================================

/* [What to show] */
// pick a part to print, or "all" to preview the assembly
part = "product"; // [product:full appliance + stand + camera aim (do NOT print), all:feeder mechanism only, rotor, housing, plate_stepper, plate_idle, hopper, board_cradle, board_cradle_stand, stand:assembled stand preview (do NOT print), base_front, base_back, support:print TWO, chute, pedestal, cam_pod:relocated OV5640 enclosure, cam_mast:drum-front camera yoke]

// export printable parts already rotated into their slicing orientation and
// sitting on z=0. Turn OFF to see a part where it lives in the machine instead.
// See the PRINT POSES block at the bottom of the file. Previews always ignore it.
PRINT_POSE = true;   // [true, false]

/* [Hidden] */

// ---- PROCESS: JLCPCB MJF / SLS, PA12 nylon ---------------------------------
// FIT is the per-side gap on every place where one PRINTED part has to go into
// or turn inside another printed part. Its size is NOT about the parts touching
// in the powder bed -- they are printed as separate solids and never touch. It
// is about TOLERANCE: MJF holds +/-0.3mm, and on a fit BOTH halves can miss in
// the direction that closes the gap. A nominal 0.3mm clearance is therefore a
// 0.3mm INTERFERENCE at the corner of the tolerance box, and the parts simply
// do not go together. 0.6 per side is the smallest number that still assembles
// when everything goes wrong at once, and is what JLCPCB publishes for MJF/SLS.
//
// Every fit below is written against FIT so they cannot drift apart. Changing
// process is then one line: FDM/SLA want 0.5, SLM/binder-jet 1.0.
//
// THIS MUST STAY ABOVE THE GEOMETRY BLOCK. OpenSCAD does not hoist top-level
// assignments -- a variable read before the line that sets it is undef, and it
// only WARNS. Defined below ROTOR_R, this silently exported a rotor with an
// undefined radius.
//
// TWO fits deliberately do NOT use it, and both are noted where they occur:
//   * the D-shaft socket -- it grips a PURCHASED steel shaft, and only the
//     printed half varies. 0.6 per side there would be 1.2mm of backlash in the
//     one joint that transmits torque.
//   * fastener clearance holes -- 0.2 per side is standard and an M3 still
//     passes a 3.6 hole that came out 0.3 small. Not a fit between two forms.
FIT = 0.6;
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

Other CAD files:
hardware/stl_jlcpcb/fixed_reupload/velapaw_chute_v2_x1.stl
hardware/stl_jlcpcb/order2_structure/velapaw_pedestal_x1.stl
hardware/stl_jlcpcb/order1_mechanism/velapaw_plate_idle_x1.stl
hardware/stl_jlcpcb/fixed_reupload/velapaw_plate_stepper_v2_x1.stl
hardware/backups/velapaw_feeder.pre-camera-pod.2026-07-26.scad
hardware/stl/hopper.stl
hardware/stl/housing.stl
hardware/stl_jlcpcb/fixed_reupload/velapaw_board_cradle_stand_v3_x1.stl
hardware/stl_jlcpcb/fixed_reupload/velapaw_hopper_v2_x1.stl
hardware/stl_jlcpcb/order1_mechanism/velapaw_housing_x1.stl
hardware/stl_jlcpcb/order1_mechanism/velapaw_plate_stepper_x1.stl
hardware/stl_jlcpcb/order1_mechanism/velapaw_support_x2.stl
hardware/stl_jlcpcb/order2_structure/velapaw_cam_mast_x1.stl
hardware/stl_jlcpcb/order2_structure/velapaw_cam_pod_x1.stl

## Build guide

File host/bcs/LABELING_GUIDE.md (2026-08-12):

# VelaPaw — Cat Body Condition Score (BCS) labeling guide

We train a 3-class estimator: **under / ideal / over**. This collapses the
standard APOP/Purina 9-point scale:

| 9-point BCS | Our class | What you see |
|---|---|---|
| 1–3 | **under**  | Ribs, spine, hip bones visible; severe waist tuck; no fat over ribs |
| 4–5 | **ideal**  | Slight waist behind ribs; ribs felt with light fat cover; minimal belly |
| 6–9 | **over** | No waist (oval from above); rounded/sagging belly fat pad; ribs hard to find |

## Folders
```
bcs_dataset/
  ideal/   <- auto-filled from Oxford-IIIT (healthy pet photos)
  under/   <- YOU collect ~200
  over/    <- YOU collect ~200
```

## How many
Aim for **~200 images per class** (balanced). Ideal is already ~190; top it up
toward ~200 if you like. The two you collect are what matter.

## Where to find under / over
- **Over:** search "obese cat", "fat cat", pet-obesity awareness sites/charts.
- **Under:** "underweight cat", "emaciated cat", "thin stray cat", shelter
  intake galleries, rescue before/after photos.

## What makes a GOOD training image
- **Side or standing full-body view** (BCS reads from the side + top). Skip
  face-only or curled-up-ball photos — the body shape must be visible.
- **One cat**, clearly the subject, reasonably in focus.
- Any lighting/background is fine (variety helps).

## Avoid these traps (breed/fur confound BCS)
- **Sphynx** looks "thin" (no fur) but can be any condition — don't auto-label under.
- **Persian / Maine Coon / Ragdoll** look round/big from fluff or frame, not fat
  — judge body shape, not fur.
- **Mix breeds across all three classes** so the model learns *condition*, not breed.
- When unsure between two classes, prefer **ideal** (conservative) or drop the image.

## After collecting
Run the prep script (resize, dedupe, 80/20 train-val split, augmentation), then
the training/export script to produce the INT8 TFLite model. The result is an
*estimate* — the app will show it with an owner-confirm + "check with your vet".

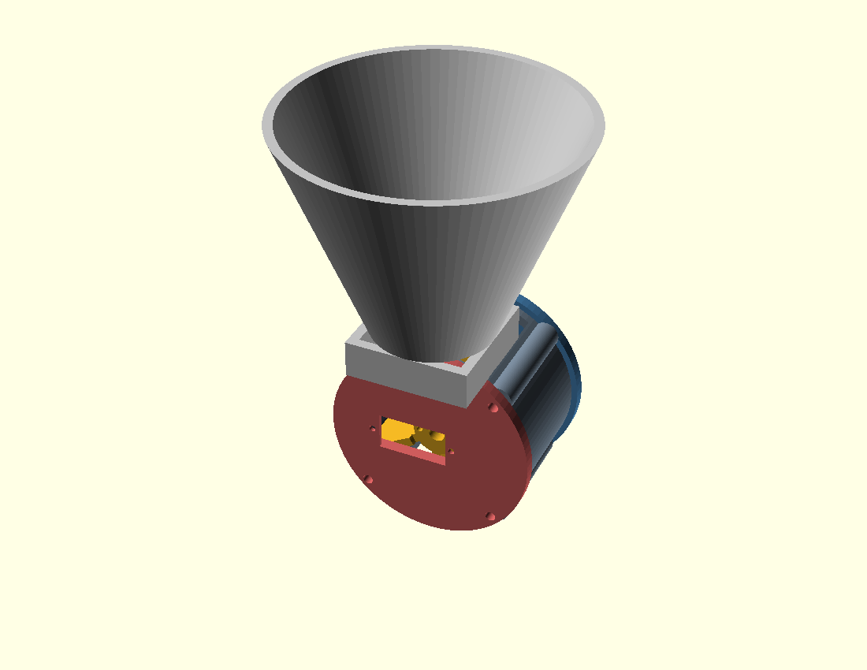
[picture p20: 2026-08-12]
hardware/preview/1_feeder_assembly.png

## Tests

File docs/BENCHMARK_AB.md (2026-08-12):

# Benchmark A/B — fast vs accurate (TSFM-Enhanced)

Host CPU, INT8 models, val=1559 imgs / 39 ids, 50 latency runs. Latency is **relative** (host, not ESP32-S3).

| metric | fast | accurate |
|---|---|---|
| tflite size (KB) | 1312 | 1403 |
| ops (count) | 8 | 9 |
| latency mean (ms) | 0.3 | 0.3 |
| latency p95 (ms) | 0.4 | 0.5 |
| intra cosine | 0.306 | 0.425 |
| inter cosine | 0.113 | 0.260 |
| separation margin | 0.192 | 0.165 |
| EER threshold | 0.140 | 0.290 |
| EER | 0.356 | 0.362 |

Ops (TFLite-Micro must support all):
- **fast**: ADD, CONV_2D, DEPTHWISE_CONV_2D, FULLY_CONNECTED, L2_NORMALIZATION, MEAN, MUL, PAD
- **accurate**: ADD, CONV_2D, DEPTHWISE_CONV_2D, FULLY_CONNECTED, L2_NORMALIZATION, LOGISTIC, MEAN, MUL, PAD

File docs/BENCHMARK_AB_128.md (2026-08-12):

# Benchmark A/B — fast vs accurate (TSFM-Enhanced)

Host CPU, INT8 models, val=1559 imgs / 39 ids, 50 latency runs. Latency is **relative** (host, not ESP32-S3).

| metric | fast | accurate |
|---|---|---|
| tflite size (KB) | 1312 | 1403 |
| ops (count) | 8 | 9 |
| latency mean (ms) | 0.5 | 0.6 |
| latency p95 (ms) | 0.6 | 0.7 |
| intra cosine | 0.346 | 0.347 |
| inter cosine | 0.103 | 0.023 |
| separation margin | 0.243 | 0.324 |
| EER threshold | 0.130 | 0.070 |
| EER | 0.328 | 0.291 |

Ops (TFLite-Micro must support all):
- **fast**: ADD, CONV_2D, DEPTHWISE_CONV_2D, FULLY_CONNECTED, L2_NORMALIZATION, MEAN, MUL, PAD
- **accurate**: ADD, CONV_2D, DEPTHWISE_CONV_2D, FULLY_CONNECTED, L2_NORMALIZATION, LOGISTIC, MEAN, MUL, PAD

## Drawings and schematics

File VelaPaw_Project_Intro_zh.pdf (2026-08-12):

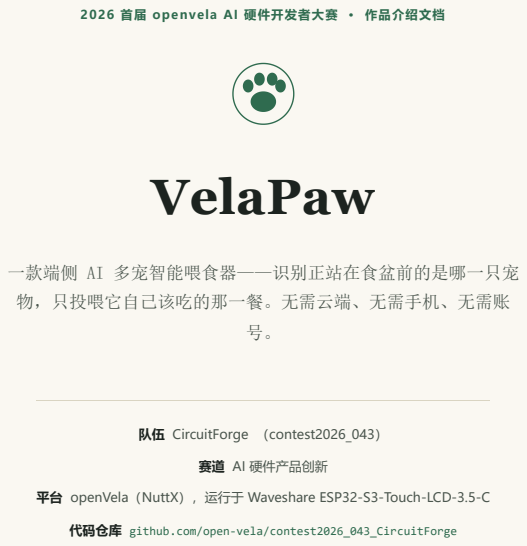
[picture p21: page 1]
VelaPaw; 队伍 CircuitForge （contest2026_043）

2026 首届 openvela AI 硬件开发者大赛 · 作品介绍文档

一款端侧 AI 多宠智能喂食器——识别正站在食盆前的是哪一只宠
物，只投喂它自己该吃的那一餐。无需云端、无需手机、无需账

赛道 AI 硬件产品创新

平台 openVela（NuttX），运行于 Waveshare ESP32-S3-Touch-LCD-3.5-C

代码仓库 github.com/open-vela/contest2026_043_CircuitForge

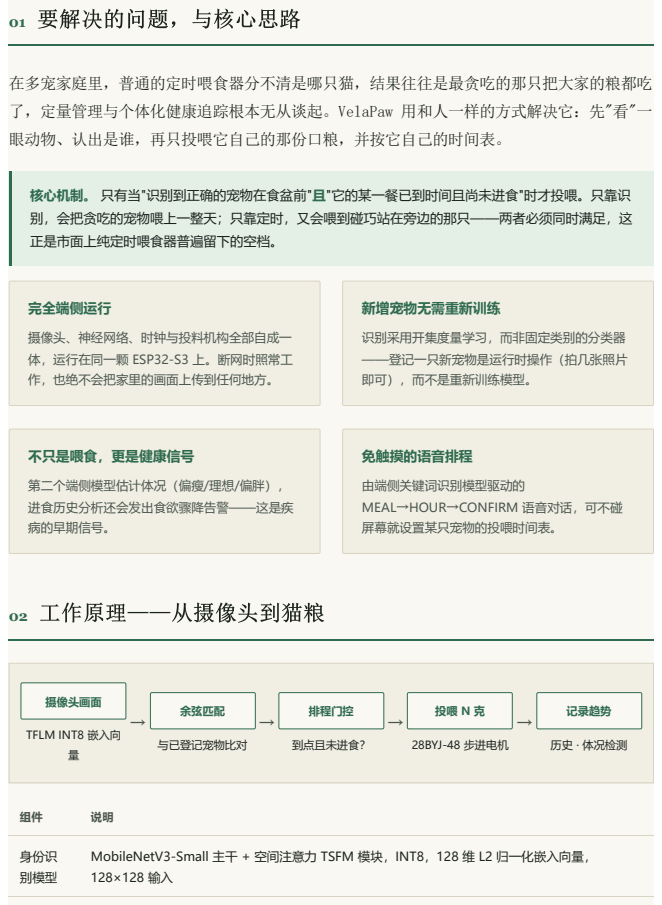
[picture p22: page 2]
01 要解决的问题，与核心思路; 完全端侧运行; 新增宠物无需重新训练; 识别采用开集度量学习，而非固定类别的分类器 ——登记一只新宠物是运行时操作（拍几张照片 即可），而不是重新训练模型。; 不只是喂食，更是健康信号; 免触摸的语音排程; 02 工作原理——从摄像头到猫粮; 摄像头画面; TFLM INT8 嵌入向 量; 余弦匹配; 与已登记宠物比对; 排程门控; 到点且未进食？; 28BYJ-48 步进电机; 记录趋势; 历史 · 体况检测; 身份识 别模型

在多宠家庭里，普通的定时喂食器分不清是哪只猫，结果往往是最贪吃的那只把大家的粮都吃
了，定量管理与个体化健康追踪根本无从谈起。VelaPaw 用和人一样的方式解决它：先"看"一
眼动物、认出是谁，再只投喂它自己的那份口粮，并按它自己的时间表。

核心机制。 只有当"识别到正确的宠物在食盆前"且"它的某一餐已到时间且尚未进食"时才投喂。只靠识
别，会把贪吃的宠物喂上一整天；只靠定时，又会喂到碰巧站在旁边的那只——两者必须同时满足，这
正是市面上纯定时喂食器普遍留下的空档。

摄像头、神经网络、时钟与投料机构全部自成一
体，运行在同一颗 ESP32-S3 上。断网时照常工
作，也绝不会把家里的画面上传到任何地方。

第二个端侧模型估计体况（偏瘦/理想/偏胖），
进食历史分析还会发出食欲骤降告警——这是疾
病的早期信号。

由端侧关键词识别模型驱动的
MEAL→HOUR→CONFIRM 语音对话，可不碰
屏幕就设置某只宠物的投喂时间表。

MobileNetV3-Small 主干 + 空间注意力 TSFM 模块，INT8，128 维 L2 归一化嵌入向量，

组件 | 说明
体况评 估模型 | 三分类（偏瘦 / 理想 / 偏胖）INT8 CNN

推理运
行时

TensorFlow Lite for Microcontrollers（apps/mlearning/tflite-micro），两个独立的 MicroInterpreter，张量内存池位于 PSRAM

加速 | Xtensa LX7 上的 ESP-NN SIMD 算子 —— 约 1.3 秒/次推理（参考算子约 6.75 秒）
模型存 放 | 开机时从闪存加载：1.44 MB 身份模型 @ 0x600000，626 KB 体况模型 @ 0x760000 —— 因体 积过大无法内存映射，由专门的开机线程读入 PSRAM

两个模型均在设备外训练（host/，TensorFlow/Keras → INT8 训练后量化 → .tflite）；身份识别模型另外配有 ArcFace 度量学习头，使嵌入向量按身份清晰分离。

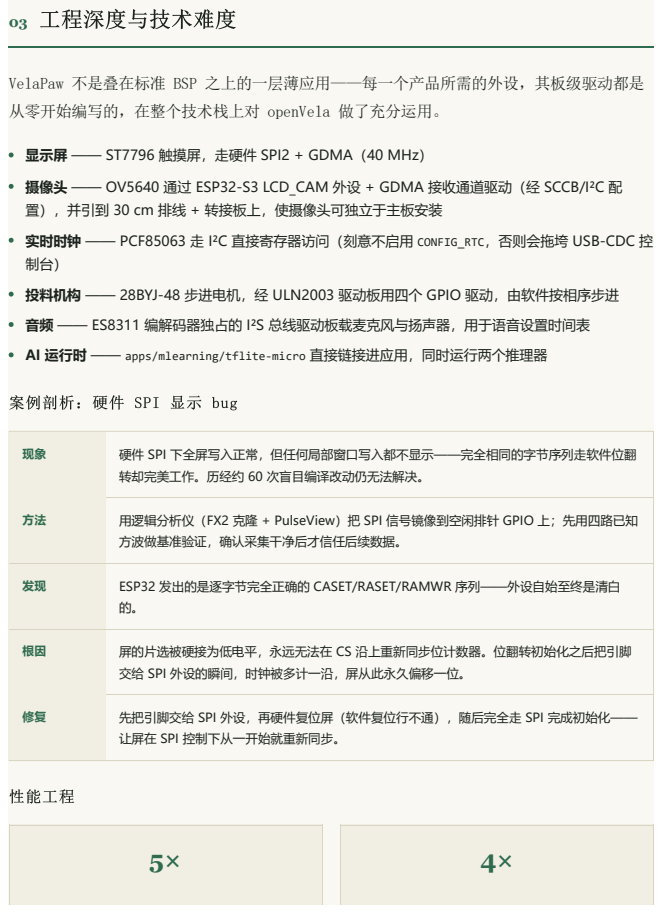
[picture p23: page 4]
03 工程深度与技术难度; 性能工程

VelaPaw 不是叠在标准 BSP 之上的一层薄应用——每一个产品所需的外设，其板级驱动都是
从零开始编写的，在整个技术栈上对 openVela 做了充分运用。

显示屏 —— ST7796 触摸屏，走硬件 SPI2 + GDMA（40 MHz）
摄像头 —— OV5640 通过 ESP32-S3 LCD_CAM 外设 + GDMA 接收通道驱动（经 SCCB/I²C 配
置），并引到 30 cm 排线 + 转接板上，使摄像头可独立于主板安装
实时时钟 —— PCF85063 走 I²C 直接寄存器访问（刻意不启用 CONFIG_RTC，否则会拖垮 USB-CDC 控
投料机构 —— 28BYJ-48 步进电机，经 ULN2003 驱动板用四个 GPIO 驱动，由软件按相序步进
音频 —— ES8311 编解码器独占的 I²S 总线驱动板载麦克风与扬声器，用于语音设置时间表

AI 运行时 —— apps/mlearning/tflite-micro 直接链接进应用，同时运行两个推理器

案例剖析：硬件 SPI 显示 bug

现象 | 硬件 SPI 下全屏写入正常，但任何局部窗口写入都不显示——完全相同的字节序列走软件位翻 转却完美工作。历经约 60 次盲目编译改动仍无法解决。

方法 | 用逻辑分析仪（FX2 克隆 + PulseView）把 SPI 信号镜像到空闲排针 GPIO 上；先用四路已知 方波做基准验证，确认采集干净后才信任后续数据。

发现 | ESP32 发出的是逐字节完全正确的 CASET/RASET/RAMWR 序列——外设自始至终是清白 的。

根因 | 屏的片选被硬接为低电平，永远无法在 CS 沿上重新同步位计数器。位翻转初始化之后把引脚 交给 SPI 外设的瞬间，时钟被多计一沿，屏从此永久偏移一位。

修复 | 先把引脚交给 SPI 外设，再硬件复位屏（软件复位行不通），随后完全走 SPI 完成初始化—— 让屏在 SPI 控制下从一开始就重新同步。

推理提速
ESP-NN SIMD 算子 · 6.75 秒 → 1.3 秒

UI 重绘提速
SPI + DMA · 246 毫秒 → 61 毫秒（全屏重绘）

### 04 硬件与结构设计

为什么选这块板——同一颗 SoC，更合适的外设

Waveshare ESP32-S3-Touch-LCD-3.5-C 搭载的是与大赛提供的 ESP32-S3-EYE 完全相同的 ESP32-S3，因此 openVela 移植、端侧推理和所有驱动都是在同一颗芯片上的工作。VelaPaw 额外需要的是一 块电容触摸屏（登记宠物、编辑投喂时间、查看趋势都在屏上完成）以及一个实时时钟（让投喂时间表在 断电后依然有效）——这块板把产品所依赖的 320×480 ST7796 触摸屏、OV5640 摄像头与 PCF85063 RTC 集成在同一块载板上。

投料机构

28BYJ-48 步进电机（经 ULN2003 驱动）驱动的叶轮投料器：叶轮每转过一格就量出一"兜"固定体积的 粮，因此份量取决于转动格数，而与料斗内余量多少无关。完整参数化 3D 模型、可打印 STL 与物料清
单见 hardware/。

摄像头位置

OV5640 从主板拔下，用 30 cm 排线 + 1:1 转接板引到位于食盆前方的独立 cam_mast 支架，从而屏幕朝 向主人、镜头对准宠物。

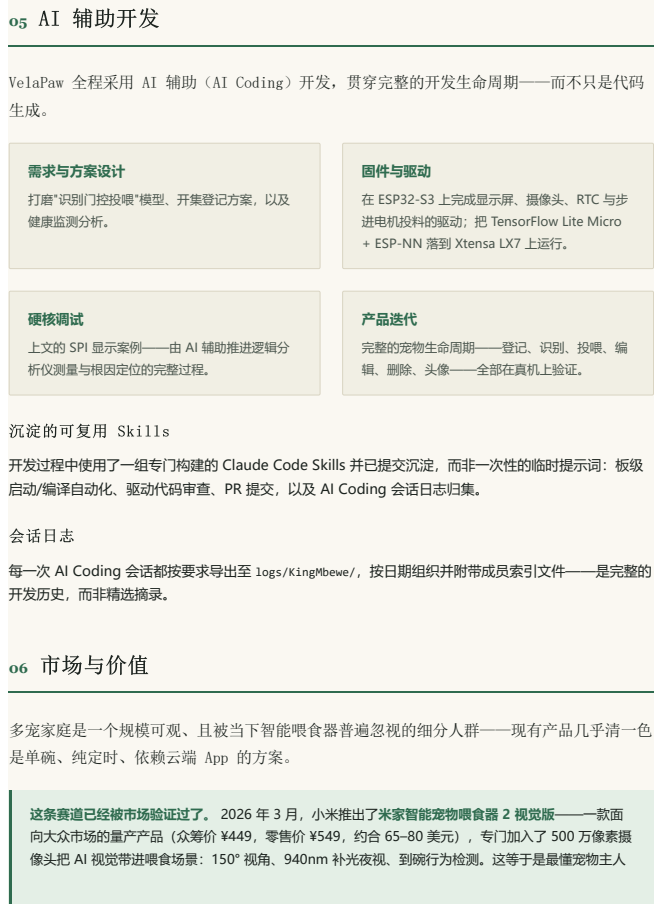
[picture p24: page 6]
05 AI 辅助开发; 06 市场与价值

VelaPaw 全程采用 AI 辅助（AI Coding）开发，贯穿完整的开发生命周期——而不只是代码

需求与方案设计
打磨"识别门控投喂"模型、开集登记方案，以及
健康监测分析。

固件与驱动
在 ESP32-S3 上完成显示屏、摄像头、RTC 与步
进电机投料的驱动；把 TensorFlow Lite Micro
+ ESP-NN 落到 Xtensa LX7 上运行。

硬核调试
上文的 SPI 显示案例——由 AI 辅助推进逻辑分
析仪测量与根因定位的完整过程。

产品迭代
完整的宠物生命周期——登记、识别、投喂、编
辑、删除、头像——全部在真机上验证。

沉淀的可复用 Skills
开发过程中使用了一组专门构建的 Claude Code Skills 并已提交沉淀，而非一次性的临时提示词：板级
启动/编译自动化、驱动代码审查、PR 提交，以及 AI Coding 会话日志归集。

会话日志
每一次 AI Coding 会话都按要求导出至 logs/KingMbewe/，按日期组织并附带成员索引文件——是完整的
开发历史，而非精选摘录。

多宠家庭是一个规模可观、且被当下智能喂食器普遍忽视的细分人群——现有产品几乎清一色
是单碗、纯定时、依赖云端 App 的方案。

这条赛道已经被市场验证过了。 2026 年 3 月，小米推出了米家智能宠物喂食器 2 视觉版——一款面
向大众市场的量产产品（众筹价 ¥449，零售价 ¥549，约合 65–80 美元），专门加入了 500 万像素摄
像头把 AI 视觉带进喂食场景：150° 视角、940nm 补光夜视、到碗行为检测。这等于是最懂宠物主人

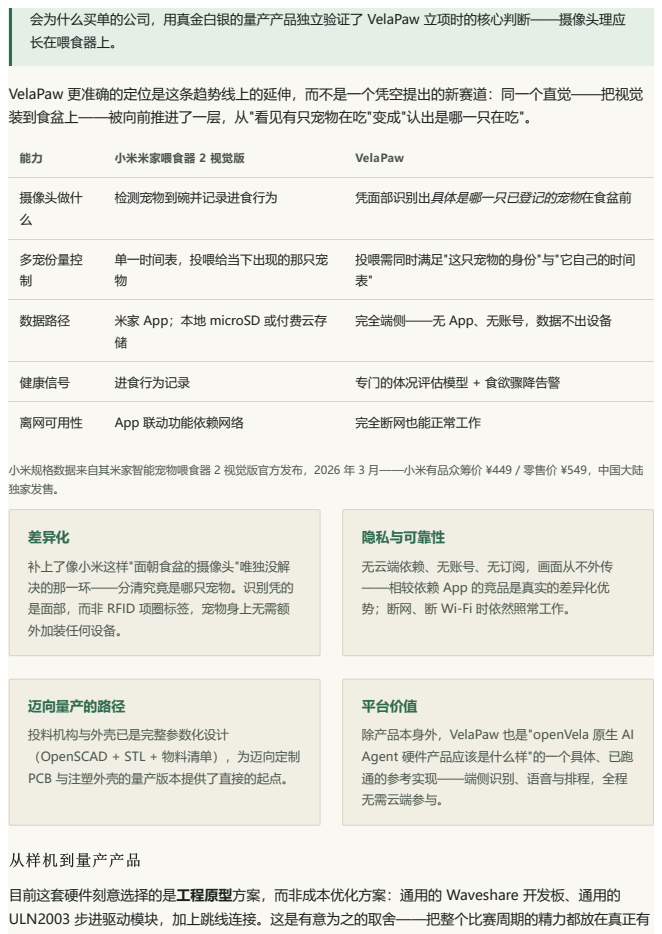
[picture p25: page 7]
小米米家喂食器 2 视觉版; VelaPaw; 摄像头做什 么; 检测宠物到碗并记录进食行为; 凭面部识别出具体是哪一只已登记的宠物在食盆前; 多宠份量控 制; 单一时间表，投喂给当下出现的那只宠 物; 数据路径; 米家 App；本地 microSD 或付费云存; 健康信号; 进食行为记录; 专门的体况评估模型 + 食欲骤降告警; 离网可用性; App 联动功能依赖网络; 完全断网也能正常工作; 差异化; 隐私与可靠性

会为什么买单的公司，用真金白银的量产产品独立验证了 VelaPaw 立项时的核心判断——摄像头理应
长在喂食器上。

VelaPaw 更准确的定位是这条趋势线上的延伸，而不是一个凭空提出的新赛道：同一个直觉——把视觉
装到食盆上——被向前推进了一层，从"看见有只宠物在吃"变成"认出是哪一只在吃"。

投喂需同时满足"这只宠物的身份"与"它自己的时间

完全端侧——无 App、无账号，数据不出设备

小米规格数据来自其米家智能宠物喂食器 2 视觉版官方发布，2026 年 3 月——小米有品众筹价 ¥449 / 零售价 ¥549，中国大陆
独家发售。

补上了像小米这样"面朝食盆的摄像头"唯独没解
决的那一环——分清究竟是哪只宠物。识别凭的
是面部，而非 RFID 项圈标签，宠物身上无需额
外加装任何设备。

无云端依赖、无账号、无订阅，画面从不外传
——相较依赖 App 的竞品是真实的差异化优
势；断网、断 Wi-Fi 时依然照常工作。

迈向量产的路径
投料机构与外壳已是完整参数化设计
（OpenSCAD + STL + 物料清单），为迈向定制
PCB 与注塑外壳的量产版本提供了直接的起点。
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

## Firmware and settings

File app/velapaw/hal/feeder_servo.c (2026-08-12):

/****************************************************************************
 * VelaPaw - feeder HAL: real servo backend (ESP32-S3 LEDC/PWM on GPIO43)
 *
 * The PWM itself lives in the board file (it owns the LEDC registers; the
 * camera's XCLK already uses ch0/timer0, so the servo takes ch1/timer1 @50Hz).
 * Here we only bridge the app API to it.
 *
 * IMPORTANT: board_feeder_dispense() SLEEPS while the gate is held open
 * (grams x SERVO_MS_PER_GRAM, e.g. ~1.8 s for 15 g). Calling that from the UI
 * task would freeze the screen + camera -- the same class of bug as a blocking
 * printf. So we run it on a detached worker thread and return immediately;
 * the UI keeps rendering while the food drops.
 ****************************************************************************/

#include <stdio.h>
#include <stdint.h>
#include <pthread.h>

#include "hal/feeder.h"

/* Provided by the board (nuttx/boards/.../esp32s3_st7789.c) */
extern void board_feeder_init(void);
extern int  board_feeder_dispense(int grams);

static void *dispense_thread(void *arg)
{
  int grams = (int)(intptr_t)arg;
  board_feeder_dispense(grams);
  return NULL;
}

int velapaw_feeder_init(void)
{
  /* The board already inits the servo at boot (board_lcd_initialize), so this
   * is a no-op; kept so the HAL contract is unchanged. */
  return 0;
}

int velapaw_feeder_dispense(int grams)
{
  pthread_t th;
  pthread_attr_t attr;

  if (grams <= 0)
    {
      return -1;
    }

  pthread_attr_init(&attr);
  pthread_attr_setstacksize(&attr, 2048);
  if (pthread_create(&th, &attr, dispense_thread,
                     (void *)(intptr_t)grams) != 0)
    {
      pthread_attr_destroy(&attr);
      return -1;
    }
  pthread_detach(th);
  pthread_attr_destroy(&attr);

  printf("    [feeder] servo dispensing %d g (async)\n", grams);
  return 0;
}

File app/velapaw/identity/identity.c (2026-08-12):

/****************************************************************************
 * VelaPaw - enrollment store + cosine matcher (in-memory)
 *
 * Persistence is delegated to store/ (stub for now). Embeddings are assumed
 * L2-normalized, so cosine similarity == dot product.
 ****************************************************************************/

#include <string.h>
#include <math.h>
#include <stdio.h>
#include <stdint.h>
#include <pthread.h>
#include "identity/identity.h"

static struct velapaw_pet g_pets[VELAPAW_MAX_PETS];
static int                g_npets;

/****************************************************************************
 * Flash persistence: enrolled pets survive a reset / power-off.
 *
 * Layout at VELAPAW_PET_FLASH_OFF (well past the models @0x600000 / @0x760000):
 *   magic "VPAW" | version | npets | g_pets[npets]      (raw POD copy)
 * A blank or garbage sector fails the magic check and reads as "no pets",
 * so we never restore nonsense.
 *
 * IMPORTANT: erase/write SUSPEND THE FLASH CACHE, so they must not run on a
 * PSRAM stack (the velapaw task's stack is PSRAM). Same trap the model loader
 * hit -- so, like backend_tflm.cc, we run them on a pthread whose stack is an
 * internal-RAM .bss buffer.
 ****************************************************************************/

extern int spi_flash_read(uint32_t src, void *dst, uint32_t size);
extern int spi_flash_write(uint32_t dst, const void *src, uint32_t size);
extern int spi_flash_erase_range(uint32_t start, uint32_t size);

#define VELAPAW_PET_FLASH_OFF  0x800000u          /* 8MB mark, past the models */
#define VELAPAW_PET_MAGIC      0x57415056u        /* "VPAW" */
#define VELAPAW_PET_VERSION    1u

/* Header only (12 B). We deliberately do NOT keep a serialization copy of the
 * pets -- we write/read g_pets[] in place, so the RAM cost here is just the
 * header + the flash thread stack (~4 KB), not another 4.5 KB of pets. */
struct pet_hdr { uint32_t magic; uint32_t version; uint32_t npets; };

#define PET_HDR_RESERVED  16u                     /* keeps pets 16-B aligned */
#define PET_AREA_BYTES    8192u                   /* 2 x 4 KB flash sectors  */

static struct pet_hdr g_hdr;                      /* 12 bytes, .bss          */
static uint8_t g_pet_flash_stack[4096];           /* internal-RAM stack      */

/* --- per-pet card icons ---------------------------------------------------
 * Kept in a SEPARATE flash region from the pet record so old pets still load,
 * and written only at enroll/delete (not on every schedule edit). The icon
 * buffers live in .bss (internal SRAM), so the flash write reads them
 * coherently while the cache is suspended -- no PSRAM bounce needed. */
#define VELAPAW_ICON_PX        (VELAPAW_ICON_W * VELAPAW_ICON_H)
#define VELAPAW_ICON_FLASH_OFF 0x810000u          /* past the pet record       */
#define VELAPAW_ICON_MAGIC     0x4E434956u        /* "VICN"                    */
#define VELAPAW_ICON_AREA_BYTES 32768u            /* 8 x 4 KB sectors          */

static uint16_t g_icon[VELAPAW_MAX_PETS][VELAPAW_ICON_PX];  /* ~25 KB .bss     */
static uint8_t  g_icon_valid[VELAPAW_MAX_PETS];             /* has an icon?    */
struct icon_hdr { uint32_t magic; uint32_t version; };
static struct icon_hdr g_ihdr;

struct pet_io { int write; int rc; };

/* Runs on the internal-RAM-stack thread: flash erase/write suspend the cache,
 * so none of this may execute on the velapaw task's PSRAM stack. */
static void *pet_flash_thread(void *arg)
{
  struct pet_io *io = (struct pet_io *)arg;

  if (io->write)
    {
      io->rc = spi_flash_erase_range(VELAPAW_PET_FLASH_OFF, PET_AREA_BYTES);
      if (io->rc >= 0)
        {
          io->rc = spi_flash_write(VELAPAW_PET_FLASH_OFF, &g_hdr, sizeof(g_hdr));
        }
      if (io->rc >= 0)
        {
          io->rc = spi_flash_write(VELAPAW_PET_FLASH_OFF + PET_HDR_RESERVED,
                                   g_pets, sizeof(g_pets));
        }
    }
  else
    {
      io->rc = spi_flash_read(VELAPAW_PET_FLASH_OFF, &g_hdr, sizeof(g_hdr));
      if (io->rc >= 0 &&
          g_hdr.magic   == VELAPAW_PET_MAGIC &&
          g_hdr.version == VELAPAW_PET_VERSION &&
          g_hdr.npets   <= VELAPAW_MAX_PETS)
        {
          /* header is good -> only now do we overwrite g_pets */
          io->rc = spi_flash_read(VELAPAW_PET_FLASH_OFF + PET_HDR_RESERVED,
                                  g_pets, sizeof(g_pets));
        }
      else
        {
          io->rc = -1;                            /* blank/garbage -> no pets */
        }
    }
  return NULL;
}

static int pet_flash_run(int write)
{
  struct pet_io io = { write, -1 };
  pthread_attr_t attr;
  pthread_t th;
  pthread_attr_init(&attr);
  pthread_attr_setstack(&attr, g_pet_flash_stack, sizeof(g_pet_flash_stack));
  if (pthread_create(&th, &attr, pet_flash_thread, &io) != 0)
    {
      pthread_attr_destroy(&attr);
      return -1;
    }
  pthread_join(th, NULL);
  pthread_attr_destroy(&attr);
  return io.rc;
}

int velapaw_identity_save(void)
{
  g_hdr.magic   = VELAPAW_PET_MAGIC;
  g_hdr.version = VELAPAW_PET_VERSION;
  g_hdr.npets   = (uint32_t)g_npets;
  int rc = pet_flash_run(1);
  printf("velapaw/identity: saved %d pet(s) to flash rc=%d\n", g_npets, rc);
  return rc;
}

/* Icon flash I/O, same internal-RAM-stack pattern as the pets. Reuses the pet
 * flash stack (they never run at the same time). */
static void *icon_flash_thread(void *arg)
{
  struct pet_io *io = (struct pet_io *)arg;

  if (io->write)
    {
      g_ihdr.magic = VELAPAW_ICON_MAGIC; g_ihdr.version = 1;
      io->rc = spi_flash_erase_range(VELAPAW_ICON_FLASH_OFF,
                                     VELAPAW_ICON_AREA_BYTES);
      if (io->rc >= 0)
        io->rc = spi_flash_write(VELAPAW_ICON_FLASH_OFF, &g_ihdr, sizeof(g_ihdr));
      if (io->rc >= 0)
        io->rc = spi_flash_write(VELAPAW_ICON_FLASH_OFF + 16,
                                 g_icon_valid, sizeof(g_icon_valid));
      if (io->rc >= 0)
        io->rc = spi_flash_write(VELAPAW_ICON_FLASH_OFF + 32,
                                 g_icon, sizeof(g_icon));
    }
  else
    {
      io->rc = spi_flash_read(VELAPAW_ICON_FLASH_OFF, &g_ihdr, sizeof(g_ihdr));
      if (io->rc >= 0 && g_ihdr.magic == VELAPAW_ICON_MAGIC)
        {
          spi_flash_read(VELAPAW_ICON_FLASH_OFF + 16,
                         g_icon_valid, sizeof(g_icon_valid));
          spi_flash_read(VELAPAW_ICON_FLASH_OFF + 32, g_icon, sizeof(g_icon));
        }
      else
        {
          io->rc = -1;                         /* blank/old flash -> no icons */
        }
    }
  return NULL;
}
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

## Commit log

2026-06-26 Initial commit: scaffold contest repo for team CircuitForge
2026-08-12 Add VelaPaw: multi-pet smart feeder with on-device face recognition
    Replaces the org scaffold with the full contest submission: ESP32-S3
    firmware (camera-gated feeding, voice-scheduled meals, LVGL UI with
    EN/中文 support), the on-device identity/inference pipeline, host-side
    training tooling, hardware design files, documentation, and AI-coding
    session logs.
    [board_cradle.stl, board_cradle_stand.stl, hopper.stl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]
